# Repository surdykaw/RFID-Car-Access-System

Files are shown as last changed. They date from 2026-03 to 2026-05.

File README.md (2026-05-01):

# RFID Car Access System







## Project Overview
Embedded access control system for vehicle central locking using RFID authentication.

This project implements a standalone hardware module that allows a car to be locked or unlocked by presenting an RFID tag near the vehicle window. The system reads RFID tags using an MFRC522 reader and authenticates them using an ATmega8A microcontroller.

When a valid tag is detected, the microcontroller toggles the lock state and simulates the vehicle's internal lock/unlock button using transistor-based driver circuits. Locking and unlocking are performed alternately.

The project includes:

- custom embedded firmware written in C (for AVR)
- RFID interface implementation for MFRC522 reader
- watchdog-based system reliability
- custom hardware prototype
- full system documentation

The system was designed as a **complete embedded project**, including both firmware and hardware development.

---
## Demo

The animation below shows the system detecting an RFID tag placed against the car window.  
When a valid tag is detected, the system toggles the lock state and the status LED indicates system activity - locking / unlocking state.

System demo

---
## Features

- RFID authentication using MFRC522 reader
- configurable list of authorized RFID tags
- SPI communication between MFRC522 and ATmega8A
- watchdog-based system recovery and reliability
- protection against repeated unauthorized access attempts
- transistor-based drivers for lock and unlock control signals
- modular firmware structure (RFID, SPI, watchdog, system config)
- designed and implemented as a full hardware + firmware embedded project

---
## System Architecture
The system consists of three main functional blocks:

1. **RFID Interface** – MFRC522 reader responsible for detecting and reading RFID tags.
2. **Control Unit** – ATmega8A microcontroller together with supporting hardware (voltage regulator, transistor drivers, LED indicator and firmware responsible for authentication and system logic).
3. **Lock Control Stage** – transistor-based driver circuits used to simulate the vehicle's lock and unlock button signals.

### System Data Flow
<pre>
RFID Tag
   ↓
MFRC522 RFID Reader
   ↓ Serial Peripheral Interface (SPI)
ATmega8A Control Unit
   ↓
Transistor Driver Circuit
   ↓
Vehicle Central Lock Controller
</pre>

### Authentication Flow

1. The system checks for nearby RFID tags every second.
2. When a tag is detected, its UID is read through the SPI interface.
3. The UID is compared with a list of authorized tags stored in firmware.
4. If authentication succeeds, the system toggles the lock state.
5. The microcontroller activates the appropriate transistor driver to simulate a lock or unlock button press.
6. Invalid authentication attempts increase a counter and may trigger a temporary lockout.

The firmware uses a watchdog timer to recover from potential communication errors with the RFID reader.

---
## Hardware

The system hardware is built around an **ATmega8A microcontroller** and an **MFRC522 RFID reader module**.  
The device was initially prototyped on a soldered prototype board and later integrated into the vehicle.

### Hardware Prototype

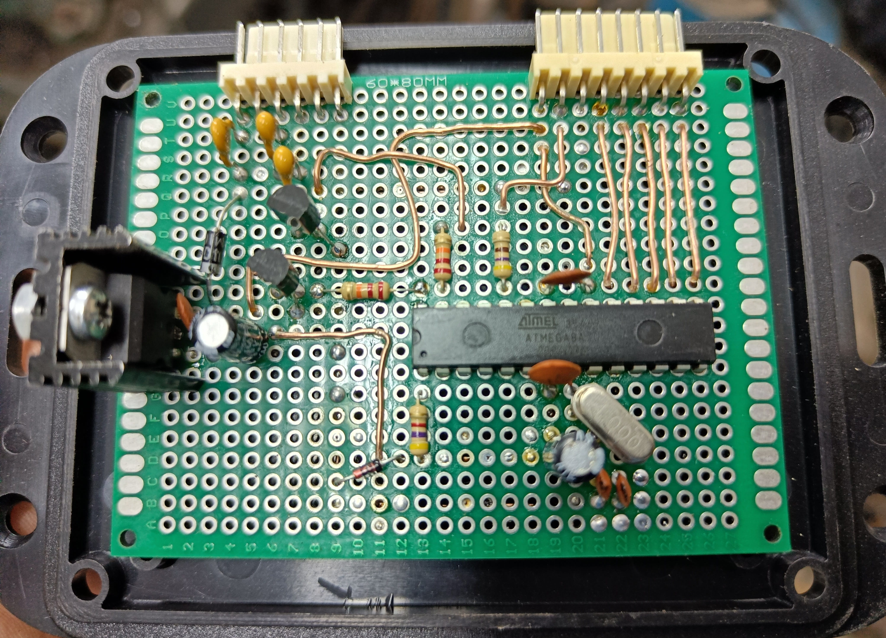
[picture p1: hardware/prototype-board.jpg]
Prototype board


The prototype includes the following key components:

- **ATmega8A microcontroller** – main control unit responsible for RFID authentication logic
- **MFRC522 RFID reader** – detects and reads RFID tags
- **LD1117 voltage regulator** – provides stable 3.3V supply for the entire access control system
- **BC547B transistors** – used as switching drivers for lock and unlock signals
- **Status LED (blue)** – indicates system activity
- **External 4 MHz crystal oscillator** – provides system clock for the microcontroller

In addition to the main components, the circuit also includes supporting elements such as:
- current limiting resistors
- filtering and decoupling capacitors
- signal conditioning components

### Circuit Schematic

During early development the circuit was designed using a hand-drawn schematic, available at:

[**hardware/handmade-schematic-diagram.png**](hardware/handmade-schematic-diagram.png)

A cleaned-up schematic was recreated in **KiCad** and was shown just below.

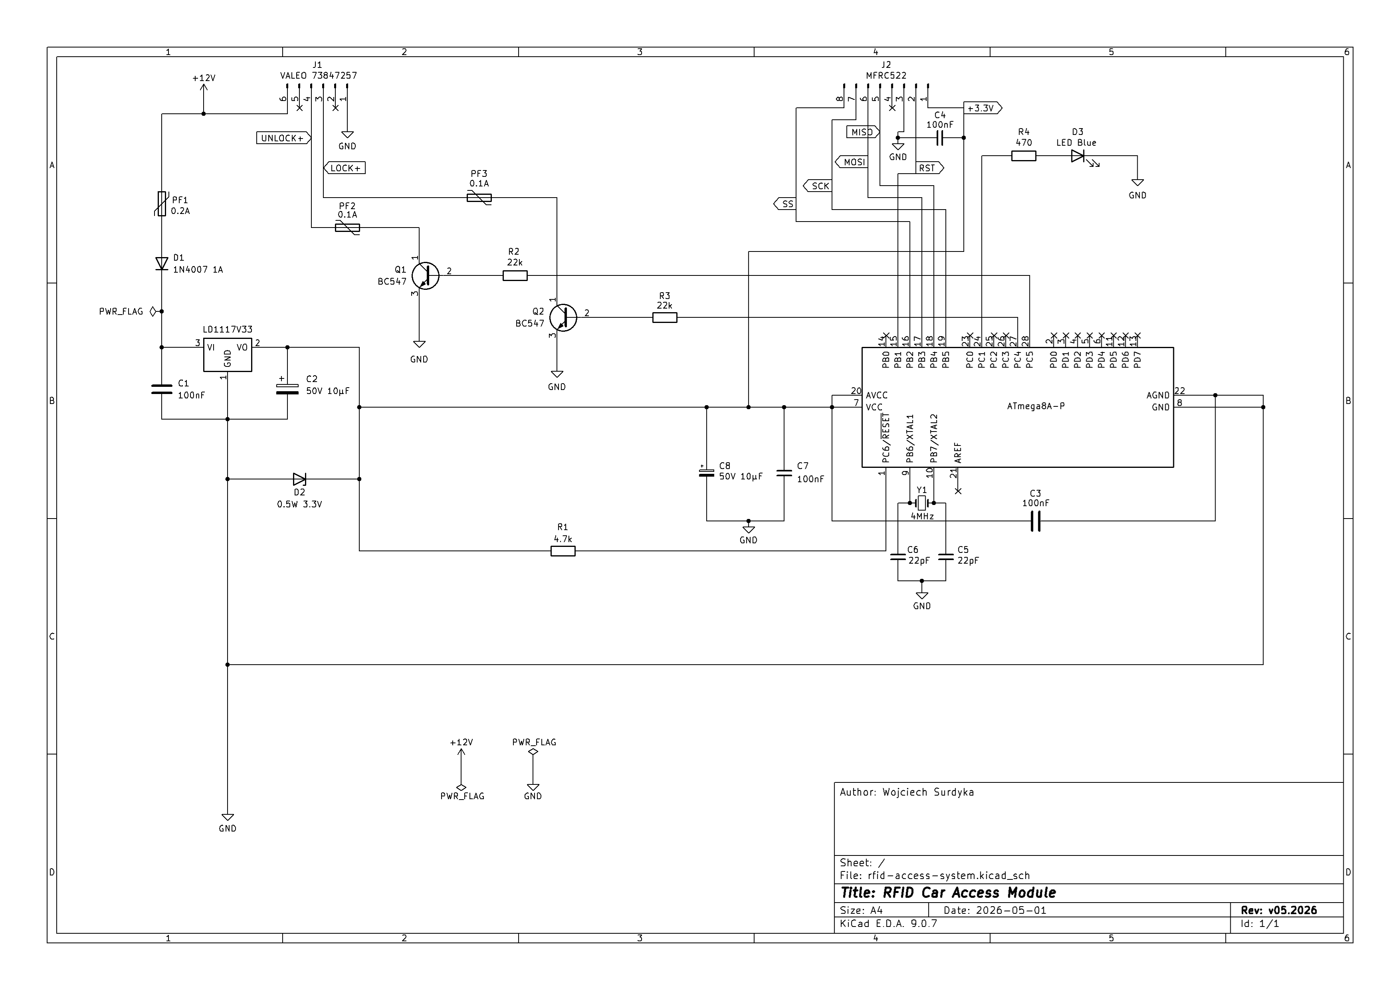
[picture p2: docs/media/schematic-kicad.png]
Final_schematic


See [**docs/kicad-project-files/**](docs/kicad-project-files/) to reach all the **KiCad** project files.

---
## Firmware

The firmware is written in **C (for AVR)** using the **AVR-GCC** toolchain and follows a modular structure.

Project structure

<pre>
firmware
├── main.c
├── include
│     ├── mfrc522-config.h
│     ├── mfrc522.h
│     ├── spi-config.h
│     ├── system-config.h
│     └── wdt-config.h
│
└── src
      ├── mfrc522.c
      ├── spi-config.c
      └── wdt-config.c
</pre>

### Main Firmware Modules

**RFID module (`mfrc522`)**

Handles communication with the MFRC522 RFID reader, including:
- register access
- FIFO communication
- tag detection
- UID retrieval

**SPI interface (`spi-config`)**

Implements low-level SPI communication between the ATmega8A and the MFRC522 reader.

**Watchdog module (`wdt-config`)**

Provides system reliability by enabling the watchdog timer and recovering from unexpected firmware states.

**System configuration (`system-config`)**

Stores configuration parameters such as:

- authorized RFID tag UIDs
- GPIO pin definitions
- lock control configuration

### Main Control Loop

The firmware operates using a continuous polling loop.

Simplified workflow:

1. Initialize SPI interface
2. Initialize RFID reader
3. Continuously scan for RFID tags
4. Read tag UID when detected
5. Validate UID against authorized list
6. Toggle lock state if authentication succeeds
7. Handle invalid authentication attempts
8. Recover from communication errors if necessary
9. Maintain system stability using watchdog timer

---
## Vehicle Integration

The RFID access system integrates with the vehicle's central locking system by electrically simulating the signals generated by the original lock/unlock button.

Instead of modifying the vehicle controller directly, the system uses transistor-based switching circuits to momentarily close either the lock or unlock control lines of the central locking controller.

The access system is powered directly from the vehicle's 12V central locking controller supply and internally regulated to 3.3V for the microcontroller and RFID reader.

A detailed description of the integration process, signal analysis and electrical interface can here:

> 📖 Detailed vehicle integration description: [**docs/vehicle-integration.md**](docs/vehicle-integration.md)

---
## Build Instructions

First, download the repository using `git clone` command, as shown right below:
```
git clone https://github.com/surdykaw/RFID-Car-Access-System.git
```
or just download the entire repository as a ZIP folder.

The firmware is built using avr-gcc compiler with avr-libc package and a Makefile-based build system.

Building the firmware project was tested on:

-   **Linux (Debian)**
-   **Windows using MSYS2 (MINGW64 environment)**

The Makefile uses UNIX-like shell commands such as:

`mkdir`
`rm`

For this reason, on Windows it is recommended to use a POSIX-compatible shell such as:

-   MSYS2 (recommended)
-   Git Bash
-   WSL

### Toolchain Requirements
> [!IMPORTANT]
> The following tools are required:
>-   `avr-gcc`
>-   `avr-libc`
>-   `avrdude`
>-   `make`

### Linux Installation Example

On Debian/Ubuntu-based systems:

```
sudo apt install avr-gcc avr-libc avrdude make
```

### Windows (MSYS2) Installation

Install MSYS2 and then install the AVR toolchain:

```
pacman -S avr-gcc avr-libc avrdude make
```

Use the MINGW64 terminal to build the project.

### Building the Firmware

To compile the firmware run:

```
make build
```

The build process will:

1.  Create the build/ directory
2.  Compile the firmware using avr-gcc
3.  Generate the Intel HEX file using avr-objcopy
4.  Display firmware memory usage using avr-size

Generated files:
<pre>
build/firmware.elf
build/firmware.hex
</pre>
### Flashing the Firmware

The firmware can be uploaded using a USBasp programmer.
Run:
```
make flashupdate
```
The `make flashupdate` indeed executes the one below:

`
avrdude -c usbasp -p m8a -U flash:w:build/firmware.hex
`

Required hardware:

-   **USBasp programmer**
-   **connection to the ATmega8A ISP interface**

### Cleaning Build Files

To remove all generated files run:
```
make clean
```
> [!NOTE]
> This command removes the entire **build/** directory.

---
## License
This project is released under the **MIT License**.

See the `LICENSE` file for details.

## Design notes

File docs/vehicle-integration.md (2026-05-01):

# Vehicle Integration

This document describes how the RFID access control module was integrated with the vehicle's central locking system.

> [!Note]
> The terms *controller* and *decoder* refer to the same central locking module in the vehicle.

The goal was to add RFID-based lock/unlock functionality without modifying the internal electronics of the vehicle's central locking controller.

Instead of controlling the door lock actuators directly, the system electrically simulates the original lock/unlock signals for the central locking button located inside the vehicle cabin.

The integration described in this document was performed on a vehicle equipped with the following central locking decoder:

**Manufacturer:** VALEO  
**Decoder model:** 73847257

---
# Central Lock Button Interface

The vehicle includes a physical button on the dashboard that allows locking and unlocking all doors.

The button works by closing specific control lines connected to the central locking controller.

Pressing the button connects the control line to ground, which is interpreted by the decoder as a lock or unlock request.

The RFID access control system replicates this behavior by momentarily closing the same control lines.

---
# Integration Point

The access control system module is connected in parallel with the original lock/unlock button wiring.

Two control lines are used:

- **Unlock line**
- **Lock line**

The original button remains fully functional because the RFID module only momentarily closes the same electrical path used by the button.

---
# Transistor Switching Interface

The connection between the microcontroller and the vehicle control lines is implemented using two **NPN transistor switches**.

Each transistor acts as a low-side switch controlled by the microcontroller.

This is electrically equivalent to pressing the physical dashboard button.

The firmware keeps the transistor active for approximately **1 second**, which replicates a typical manual button press.

---
# Power Supply

The access system module is powered directly from the **12V supply available at the central locking controller**.

The internal electronics of the RFID system operate at **3.3V**, therefore a voltage regulator is used.

Power path
```
Vehicle 12V
↓
LD1117 voltage regulator
↓
3.3V system supply
↓
ATmega8A + MFRC522
```

---
# Design Considerations
The integration method was chosen to minimize risk and avoid modifying the original vehicle electronics.

Key properties of this approach:

- no modification of the central locking controller
- original dashboard button remains functional
- the RFID module only simulates an existing control input
- electrical interface implemented using transistor switches

This ensures that the system behaves like a standard control input rather than an external actuator driver.

---
# Notes
The exact wiring and signal logic may vary between vehicle models.

The integration described here is specific to the vehicle model used during development.
Adapting the system to another vehicle requires analyzing its central locking control scheme and identifying the corresponding control lines.

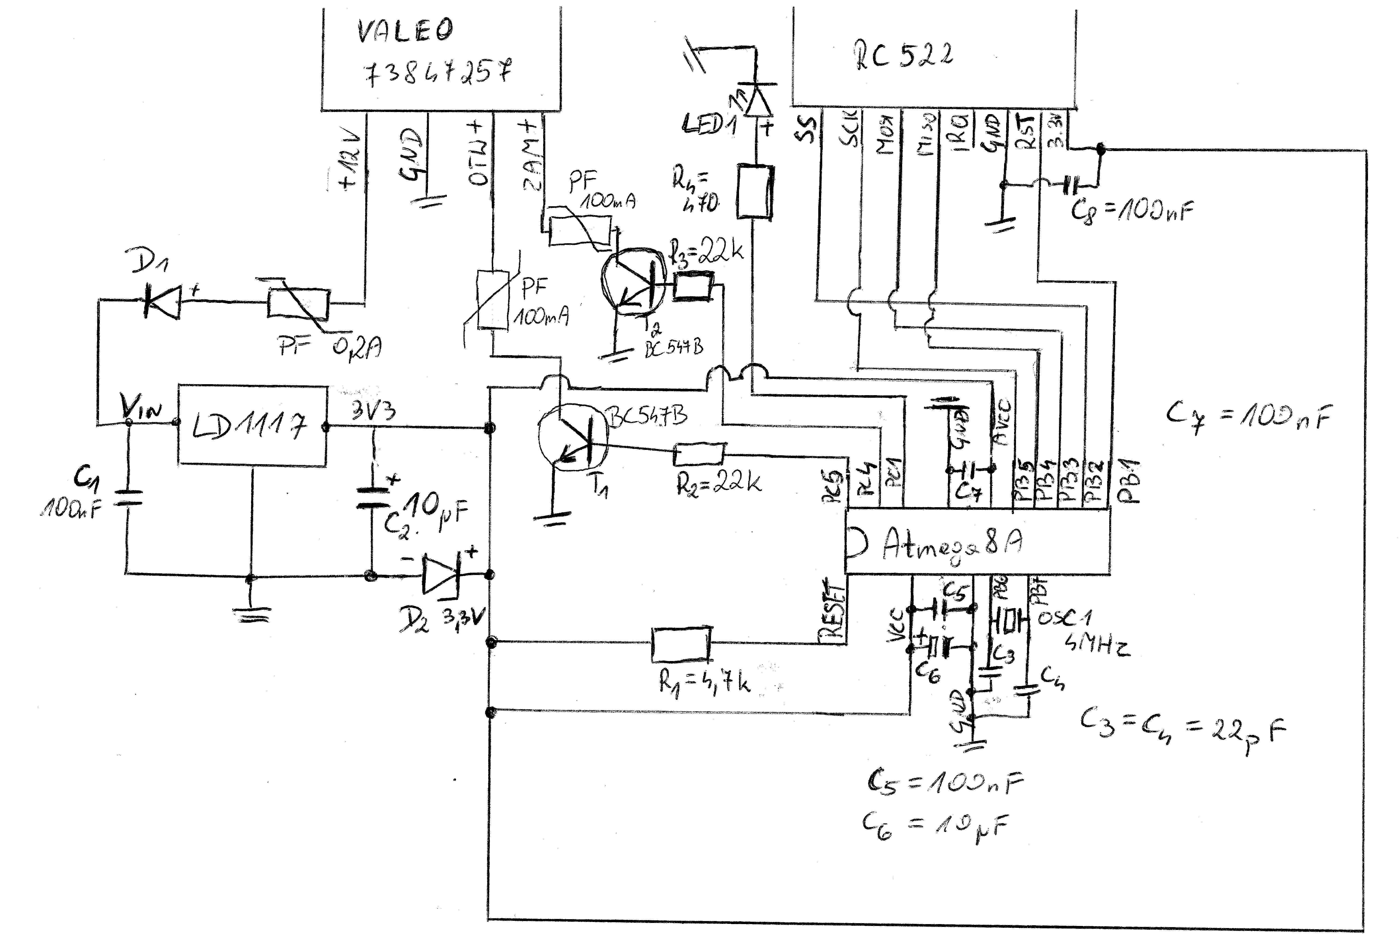
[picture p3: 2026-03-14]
hardware/handmade-schematic-diagram.png

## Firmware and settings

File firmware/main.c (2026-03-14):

#include <avr/io.h>
#include <util/delay.h>

#include "spi-config.h"
#include "mfrc522.h"
#include "wdt-config.h"
#include "system-config.h"

void setRegisters(void) {
	// DATA REGISTERS
	DDRB |= 0x0F;
	PORTB &= ~(0x01);
	DDRC |= 0x3F;
	PORTC = 0x00;
	DDRD = 0xFF;
	PORTD = 0x00;

	// MINIMIZING POWER CONSUMPTION
	ADCSRA &= ~(1 << ADEN); // Analog - Digital Converter
	ACSR &= ~(1 << ACIE);
	ACSR |= (1 << ACD); // Analog comparator
	UCSRB = 0x00; // USART Control Register
}

uint8_t validateTag(uint8_t *uid) {
    for(uint8_t tag = 0; tag < TAG_COUNT; tag++) {
        uint8_t match = 1;

        for (uint8_t i = 0; i < 4; i++) {
            if (TAGS_UID_TAB[tag][i] != uid[i]) {
                match = 0;
                break;
            }
        }
        if(match)
            return ACCESS;
    }
    return NO_ACCESS;
}

void lock() {
	PORTC |= (1 << LOCK);
	_delay_ms(1000);
	PORTC &= ~(1 << LOCK);
}

void unlock() {
	PORTC |= (1 << UNLOCK);
	_delay_ms(1000);
	PORTC &= ~(1 << UNLOCK);
}

void clearArrays(uint8_t* tagUID, uint8_t* responseFIFO) {
	for (uint8_t i = 0; i < 4; i++) {
		tagUID[i] = 0x00;
	}
	for (uint8_t i = 0; i < FIFO_BUFFER_SIZE; i++) {
		responseFIFO[i] = 0x00;
	}
}

int main(void) {
    uint8_t status;
    uint8_t tagUID[4] = {0x00};
    bool locked = true;
    uint8_t noAccessCounter = 0;
    uint8_t errorOccurred = 0;

    /* watchdog setup */
    wdtDisable(true);
    wdtEnable();
    wdtSetTimeout(WDT_TIMEOUT_2S, true);

	setRegisters();
    _delay_ms(500);

    PORTC |= (1 << INFO_LED);

    /* SPI init */
    spiInitBus();
    _delay_ms(1000);
    wdtReset();

    /* RFID init */
    mfrc522Initialize();
    _delay_ms(1000);

    PORTC &= ~(1 << INFO_LED);
    wdtReset();

    while(true) {
        status = mfrc522GetTagUID(tagUID);
        wdtReset();

        if(status == CORRECT_UID) {
        	if(validateTag(tagUID) == ACCESS) {
                PORTC |= (1 << INFO_LED);
                locked = !locked;

                if(locked)
                    lock();
                else
                    unlock();

                PORTC &= ~(1 << INFO_LED);
                noAccessCounter = 0;
                errorOccurred = 0;
                wdtReset();
            }
            else {
                noAccessCounter++;
                if(noAccessCounter > 2) {
                    noAccessCounter = 0;
                    PORTC |= (1 << INFO_LED);
                    /* 1 minute timeout */
                    for(uint8_t i = 0; i < 60; i++) {
                        _delay_ms(1000);
                        wdtReset();
                    }
                    PORTC &= ~(1 << INFO_LED);
                }
            }
            clearArrays(tagUID, rfidBuffer);
        }
        else if(status == ERROR) { // Complete reset when ERROR occurred twice
            PORTC |= (1 << INFO_LED);
            clearArrays(tagUID, rfidBuffer);
            
			if(!errorOccurred)
                errorOccurred = 1;
            else {
                errorOccurred = 0;
                /* full reader reset */
                do {
                    mfrc522HardReset();
                    _delay_ms(200);
                    spiInitBus();
                    _delay_ms(200);
                    mfrc522Initialize();
                    status = mfrc522GetTagUID(tagUID);
                } while(status == ERROR);
                wdtReset();
            }
            PORTC &= ~(1 << INFO_LED);
        }
        _delay_ms(1000);
    }

    return 0;
}

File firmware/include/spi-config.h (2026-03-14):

#pragma once

#include <stdint.h>
#include <avr/io.h>

#define SPI_DDR		DDRB
#define SPI_PORT	PORTB
#define SPI_PIN		PINB

#define SPI_SCK		PB5
#define SPI_MISO	PB4
#define SPI_MOSI	PB3
#define SPI_SS		PB2
#define SPI_RST     PB1

static inline void setSSPinLow(void) {
    SPI_PORT &= ~(1 << SPI_SS);
}

static inline void setSSPinHigh(void) {
    SPI_PORT |= (1 << SPI_SS);
}

void spiInitBus(void); // Initialization of the SPI interface of MCU
uint8_t spiTransferByte(uint8_t byteOfData); // Puts (reads) one byte on (from) a bus

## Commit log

2026-03-14 Change sizes of the handmade-schematic-diagram to better fit in the README
2026-05-01 Add final circuit schematic in KiCad
    [rfid-access-system.kicad_pcb, rfid-access-system.kicad_sch]

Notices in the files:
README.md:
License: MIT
